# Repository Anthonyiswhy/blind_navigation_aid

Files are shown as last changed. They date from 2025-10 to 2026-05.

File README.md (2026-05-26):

# BlindNav

Wearable navigation assistant for blind users built for Raspberry Pi 4 + Intel
RealSense D435. The system detects obstacles, estimates threat from distance
and time-to-collision, and speaks warnings through Bluetooth headphones using
local audio/TTS paths.

Current production version: `v3.30 HEADLESS`

- Production script: `raspberry_pi/yolo_realsense_navigation.py`
- Foundational regression suite: `tests/test_blindnav.py`
- Advanced voice/latency regression suite: `tests/test_blindnav_v326.py`
- Verified locally on May 17, 2026: `200 passed`

## What It Does

- Runs YOLO26n ONNX inference on Pi 4 CPU.
- Samples depth per tracked object using adaptive stride + clustering.
- Compensates apparent approach speed using background-depth ego-motion.
- Suppresses static-object chatter when the user is standing still.
- Speaks left/right/ahead warnings with distance-aware cooldown buckets.
- Logs per-alert latency timestamps to `events.log`.
- Provides on-demand scene description with the `d` key.
- Provides optional push-to-talk voice commands with OpenAI speech-to-text.
- Provides an optional OpenAI alert TTS field-test mode.
- Provides a local generated-alert-clip mode for high-quality safety speech
  without live cloud/Piper synthesis during walking.

## Recent Changes

### v3.30

- Added `BLINDNAV_ALERT_TTS=openai` as a field-test mode for urgent, warning,
  and cleared alert speech.
- Added `BLINDNAV_ALERT_TTS=clips` for local pre-generated alert WAV playback
  with `espeak-ng` fallback when a phrase is missing.
- In clip mode, live Piper fallback is disabled by default for queued speech so
  awareness/info messages do not unexpectedly add Pi-side synthesis latency.
- Keeps detection, threat scoring, voice queueing, and `aplay` playback policy
  unchanged so the field test compares TTS output only.
- Uses OpenAI WAV speech output with local fallback enabled by default.
- Added `tools/run_tts_local.sh`, `tools/run_tts_openai.sh`, and
  `tools/FIELD_TEST_TTS_COMPARE.md` for repeatable side-by-side field tests.

### v3.29

- Added optional push-to-talk voice command input with `BLINDNAV_VOICE_INPUT=1`.
- Records short commands with `arecord`, transcribes through OpenAI STT, and
  routes deterministic commands: describe, nearest, people, status, repeat, and
  cancel.
- Keeps safety alerts on the existing local Piper/VoiceAssistant path by
  default; OpenAI STT is used only for command input.
- Adds a thread-safe navigation snapshot so command responses can report the
  nearest object, people count, and runtime status without blocking detection.
- Adds `tools/test_transcribe.py` for command-line STT smoke testing.

### v3.28

- Bucketed spoken distances to the same 30 cm voice buckets already used by
  cooldown keys so repeat warnings reuse the same Piper phrases instead of
  synthesizing slightly different decimals.
- Added richer voice diagnostics to `events.log`, including queue wait, synth
  time, launch wait, cache hit vs miss, and synthesis mode.
- Made left/right/ahead hysteresis frame-stable so repeated same-frame position
  reads no longer consume the switch threshold early.
- Promoted nearby side-pass people on the left/right while the user is moving,
  so a person walking by no longer depends entirely on radial TTC.
- Clamped bad-ego TTC usage to close range when the user is still, blocking
  far nonsense alerts such as `person ahead, 6.4 meters`.
- Switched non-person urgent/warning phrasing to cached `obstacle` wording so
  close-object warnings stay fast even when the classifier label changes.

### v3.27

- Switched urgent/warning alerts to Piper by default while keeping `espeak`
  available as an override through `BLINDNAV_ALERT_TTS=espeak`.
- Added a prewarmed Piper alert-clip cache for common short safety phrases so
  urgent/warning speech stays natural without paying full synthesis cost every
  time.
- Kept `en_US-amy-medium` as the default Piper voice and added env-based voice
  overrides so `lessac-medium` can be tested without editing the script.
- Added large-jump confirmation and far-noise suppression so static people at
  roughly 2-3m do not accumulate fake approach velocity.
- Replaced the thirds-based left/right/ahead split with wide-angle-aware angle
  mapping plus per-track hysteresis.
- Unified filtered motion across threat scoring, TTC logging, console output,
  and CSV logging.
- Hardened shutdown so the voice queue drains cleanly and the capture thread is
  joined before process exit.

### v3.25

- Reduced ONNX Runtime to 3 threads so Piper synthesis gets CPU time.
- Added ego-Z clamp and confidence gating to block impossible velocity spikes.
- Switched to zone-based voice cooldown keys so tracker ID churn does not
  retrigger the same warning.
- Added per-alert latency logging.

### v3.26b

- Extracted `_select_voice_message()` so alert wording is unit-testable.
- Fixed neutral wording leakage in close-distance branches when ego-motion is
  unreliable.
- Added safe urgent supersession: an urgent alert can cancel a lower-priority
  phrase only while that phrase is still synthesizing.
- Replaced terminate-style preemption with BT-safe skip-ahead before playback.
- Preserved the hard rule that active `aplay` playback is never terminated.

## Hard Rules

- Never send SIGTERM to `aplay`.
- Never use `numpy` 2.0+; pin `numpy==1.26.4`.
- Never use `cv2.imshow` on the Pi; use the Flask MJPEG stream for display work.
- Never put the ghost filter inside `ObjectTracker`.
- Never announce a threat as cleared while its compensated velocity is still
  negative enough to indicate approach.

## Repository Layout

```text
blind_navigation_aid/
|-- AGENTS.md
|-- README.md
|-- SETUP.md
|-- STATUS.md
|-- raspberry_pi/
|   `-- yolo_realsense_navigation.py
|-- tests/
|   |-- test_blindnav.py
|   `-- test_blindnav_v326.py
`-- .github/workflows/tests.yml
```

## Quick Start

```bash
source ~/blindnav-venv/bin/activate
export ANTHROPIC_API_KEY="sk-..."
export OPENAI_API_KEY="sk-..."            # optional, for voice commands
export BLINDNAV_VOICE_INPUT=1             # optional, press v to speak command
python3 raspberry_pi/yolo_realsense_navigation.py
```

Press `d` for a scene description, or `v` for a voice command when enabled.
Use `Ctrl+C` to exit.

To compare alert TTS output only:

```bash
bash tools/run_tts_local.sh
OPENAI_API_KEY="sk-..." bash tools/run_tts_openai.sh
```

To use high-quality pre-generated local alert clips:

```bash
source ~/.config/blindnav/secrets.env
python3 tools/generate_alert_clips.py
bash tools/run_tts_clips.sh
```

Clip mode uses `~/blindnav_alert_clips` by default and falls back to
`espeak-ng` if a phrase clip is missing.

To test clip mode with optional non-speech proximity tones:

```bash
export BLINDNAV_LOG_UPLOAD=1
bash tools/run_tts_clips_tones.sh
```

This keeps speech for action-level alerts and adds local stereo pulses for
nearby hazards. Set `BLINDNAV_AUDIO_MODE=quiet|balanced|training` and
`BLINDNAV_TONE_VOLUME=0.0..1.0` to tune it.

To upload each completed run's CSV and event log to GitHub automatically:

```bash
export BLINDNAV_LOG_UPLOAD=1
python3 raspberry_pi/yolo_realsense_navigation.py
```

Logs are pushed to the `blindnav-field-logs` branch by default. Set
`BLINDNAV_LOG_UPLOAD_BRANCH` or `BLINDNAV_LOG_UPLOAD_REMOTE` to override that.
The uploader writes its own `upload_*.log` file under `~/blindnav_logs`.
BlindNav keeps the newest 10 navigation runs by default and prunes older
`log_*.csv` / `events_*.log` pairs on startup and shutdown. Set
`BLINDNAV_LOG_RETENTION_RUNS` to change that. When upload is enabled, startup
also retries upload for the newest previous completed run so logs from a prior
failed shutdown are not stranded locally.

## Tests

All tests run without camera hardware, a RealSense device, Piper, or an IMU.
Hardware modules are stubbed at import time.

```bash
pytest tests/test_blindnav.py tests/test_blindnav_v326.py -v
```

Current collected totals:

- `tests/test_blindnav.py`: 37 tests
- `tests/test_blindnav_v326.py`: 163 tests
- Combined: 200 tests

## Performance Notes

- Expected field FPS: roughly 8-14 depending on thermals.
- YOLO export must produce output shape `(1, 300, 6)`.
- ONNX Runtime stays on float32. INT8 was slower on Pi 4 ARM in project tests.
- Thermal throttling is still the main real-world performance limiter.

## Current Priorities

- Add a heatsink before field sessions.
- Review and merge the v3.30 repo state, then field-test it with Ricardo Salazar.
- Record bag-file scenarios for regression playback.
- Field-test push-to-talk voice input on the Pi with the real microphone.
- Field-test local Piper, OpenAI alert TTS, and generated local clips using the
  same walking route and compare `[LATENCY] play_start` in `events.log`.
- Add traffic-light color classification after the base obstacle system is
  stable.

## Design Notes

- Urgent audio is optimized for freshness, but active playback is not forcibly
  interrupted because Bluetooth stream renegotiation is worse than waiting for a
  short phrase to finish.
- Queueing, cooldown, latency, wording, and ego-motion regressions are all
  testable without hardware and are now covered in the advanced suite.

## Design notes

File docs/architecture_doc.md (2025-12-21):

# System Architecture

This document provides a detailed technical overview of the blind navigation aid system architecture.

## Table of Contents

1. [System Overview](#system-overview)
2. [Pipeline Flow](#pipeline-flow)
3. [Component Details](#component-details)
4. [Sensor Fusion Strategy](#sensor-fusion-strategy)
5. [Visual Distance Estimation](#visual-distance-estimation)
6. [Performance Optimizations](#performance-optimizations)

---

## System Overview

The system follows a vision-primary architecture where computer vision provides the primary awareness layer, validated and refined by physical distance sensors.

```
┌─────────────────────────────────────────────────────────┐
│                    INPUT LAYER                          │
│  Camera (102° FOV) + LIDAR + TOF×2 + Ultrasonic        │
└────────────────────┬────────────────────────────────────┘
                     ↓
┌─────────────────────────────────────────────────────────┐
│                  DETECTION LAYER                        │
│  YOLOv11n (320×320) → Bounding boxes + Classes         │
└────────────────────┬────────────────────────────────────┘
                     ↓
┌─────────────────────────────────────────────────────────┐
│                  TRACKING LAYER                         │
│  IoU matching → Track IDs + Velocity calculation        │
└────────────────────┬────────────────────────────────────┘
                     ↓
┌─────────────────────────────────────────────────────────┐
│              DISTANCE ESTIMATION LAYER                  │
│  Visual (bbox size) + Sensor validation → Distance      │
└────────────────────┬────────────────────────────────────┘
                     ↓
┌─────────────────────────────────────────────────────────┐
│                 ASSESSMENT LAYER                        │
│  Threat scoring → Priority queue                        │
└────────────────────┬────────────────────────────────────┘
                     ↓
┌─────────────────────────────────────────────────────────┐
│                   OUTPUT LAYER                          │
│  Buzzer frequency + Visual overlay + CSV logging        │
└─────────────────────────────────────────────────────────┘
```

---

## Pipeline Flow

### Frame Processing (Every Frame)

```python
1. Capture frame from Picamera2 (640×480 RGB)
2. Rotate 180° (camera mounting)
3. Read sensor data:
   - LIDAR (via I²C serial)
   - TOF1, TOF2, Ultrasonic (via ESP32 serial)
4. Apply median filtering (3-sample buffer)
5. Update sensor health monitors
```

### Object Detection (Every 3rd Frame)

```python
6. Letterbox resize to 320×320
7. Normalize to [0,1] and transpose to CHW
8. YOLOv11n inference
9. Postprocess:
   - Parse (1, 84, 2100) output
   - Filter by confidence (>0.30)
   - Convert to original image coordinates
   - Apply NMS (IoU threshold 0.45)
```

### Tracking & Distance (Every Frame)

```python
10. Update tracker with new detections
11. Match existing tracks using IoU (>0.4)
12. Expire old tracks (>1.0s)
13. For each track:
    a. Estimate visual distance from bbox size
    b. Assign appropriate sensor based on position
    c. Fuse visual + sensor estimates
    d. Calculate velocity from distance history
```

### Threat Assessment (Every Frame)

```python
14. Calculate threat score for each track
15. Sort by score (descending)
16. Update buzzer based on top threat
17. Log to CSV
18. Auto-save snapshot if critical threat
```

---

## Component Details

### 1. YOLOv11n Detection

**Model:** `yolo11n.onnx` (320×320 input)

**Input Shape:** `(1, 3, 320, 320)` - NCHW format

**Output Shape:** `(1, 84, 2100)` where:
- 84 = 4 box coords + 80 class confidences
- 2100 = number of anchor points (for 320×320: 80×80/4 + 40×40/4 + 20×20/4 = 2100)

**Coordinate Format:**
- `[x_center, y_center, width, height]` in pixels relative to 320×320 input
- Coordinates must be transformed back to original image space

**Postprocessing Steps:**
1. Transpose to `(2100, 84)`
2. Parse box coords (first 4 values)
3. Find best class (argmax of next 80 values)
4. Filter by confidence threshold
5. Remove letterbox padding effects
6. Scale back to original resolution
7. Apply NMS

### 2. Object Tracker

**Algorithm:** IoU-based matching

**Key Parameters:**
- `max_age`: 1.0s - Track expiry time
- `iou_threshold`: 0.4 - Minimum IoU for match
- `max_tracks`: Unlimited

**Track State:**
```python
Track {
    id: int
    class_name: str
    box: [x1, y1, x2, y2]
    score: float
    distance: int (cm)
    distance_source: str
    distance_confidence: float
    velocity: float (cm/s, negative = approaching)
    position_history: deque(5)
    distance_history: deque(5)
}
```

**Velocity Calculation:**
```python
if len(distance_history) >= 2:
    old_time, old_dist = distance_history[0]
    time_delta = current_time - old_time
    velocity = (current_dist - old_dist) / time_delta  # cm/s
```

### 3. Visual Distance Estimator

**Principle:** Inverse proportion - object size in image inversely proportional to distance

**Formula:**
```python
distance = reference_distance × (reference_pixels / actual_pixels)
```

**Calibration Data:**

| Object | Real Height (cm) | Ref Distance (cm) | Ref Pixels @ Distance |
|---|---|---|---|
| Person | 170 | 50 | 192 |
| Car | 150 | 200 | 240 |
| Bottle | 25 | 30 | 100 |
| Cup | 12 | 25 | 80 |
| Chair | 90 | 100 | 150 |
| Laptop | 25 | 40 | 120 |
| Phone | 15 | 20 | 90 |

**Confidence Calculation:**
```python
box_area_ratio = (box_area / frame_area) × 100
center_distance = distance_from_frame_center × 2
center_score = 1.0 - center_distance

confidence = box_area_ratio × center_score
# Large boxes near center = high confidence
# Small boxes at edges = low confidence
```

### 4. Sensor Fusion

**Sensor Assignment by Position:**

```
          TOF2 (Left)     LIDAR/Ultra     TOF1 (Right)
               ↖              ↑              ↗
                 \            |            /
            -0.4  \           0          /  +0.4
                   \          |        /
                    \         |       /
                     \_______FOV_____/
                           102°
```

**Position Mapping:**
```python
position = (box_center_x - frame_width/2) / (frame_width/2)
# -1.0 = left edge, 0.0 = center, +1.0 = right edge

if position > 0.3:    # Right side
    use TOF1
elif position < -0.3: # Left side
    use TOF2
else:                 # Center
    use LIDAR or Ultrasonic
```

**Confidence-Weighted Fusion:**
```python
estimates = [
    {"distance": visual_dist, "confidence": visual_conf, "valid": True},
    {"distance": sensor_dist, "confidence": sensor_conf, "valid": sensor_ok}
]

weighted_sum = Σ(distance × confidence)
total_weight = Σ(confidence)
fused_distance = weighted_sum / total_weight
```

### 5. Sensor Health Monitor

**Health Metrics:**

```python
SensorHealth {
    last_value: float
    last_change_time: float
    stuck: bool
    valid: bool
    confidence: float (0-1)
    history: deque(10)
}
```

**Checks Performed:**

1. **Stuck Detection:**
   ```python
   if abs(current - last_value) < 1.0:  # No change
       time_stuck = now - last_change_time
       if time_stuck > 0.8:  # Stuck for 0.8s
           stuck = True
           confidence *= 0.9  # Degrade gradually
   ```

2. **Range Validation:**
   ```python
   if value < min_value or value > max_value:
       valid = False
       confidence = 0.0
   ```

3. **Temporal Plausibility:**
   ```python
   apparent_speed = abs(current - last_value) / time_delta
   if apparent_speed > 400 cm/s:  # Faster than reasonable
       confidence *= 0.5  # Likely glitch
   ```

### 6. Threat Assessment

**Scoring Function:**

```python
def calculate_threat_score(track):
    score = 0.0
    
    # COMPONENT 1: Distance urgency
    if distance < 50:
        # Exponential urgency in critical zone
        score += 100 × exp(-(distance / 20))
    elif distance < 150:
        # Linear urgency in warning zone
        score += 50 × (150 - distance) / 150
    elif distance < 300:
        # Low urgency in awareness zone
        score += 10 × (300 - distance) / 300
    
    # COMPONENT 2: Velocity factor
    if velocity < -5:  # Approaching
        score += abs(velocity) × 5
        if velocity < -20:  # Fast approach
            score += 50  # Danger bonus
    elif velocity > 5:  # Moving away
        score × 0.5  # Reduce urgency
    
    # COMPONENT 3: Object type weight
    weights = {
        "train": 4.0, "truck": 3.5, "bus": 3.5,
        "car": 3.0, "motorcycle": 2.5, "bicycle": 2.0,
        "person": 1.5, "dog": 1.3,
        "chair": 0.8, "bench": 0.9, "plant": 0.7,
        "bottle": 0.3, "cup": 0.3
    }
    score × weights.get(type, 1.0)
    
    # COMPONENT 4: Confidence adjustment
    if track.score > 0.7:
        score × 1.2  # High confidence detection
    elif track.score < 0.3:
        score × 0.8  # Low confidence detection
    
    return score
```

**Threat Levels:**

| Level | Score Range | Buzzer Frequency | Action |
|---|---|---|---|
| CRITICAL | >80 | 1200-1500 Hz | Immediate alert |
| WARNING | 40-80 | 800-1200 Hz | Strong warning |
| CAUTION | 10-40 | 400-800 Hz | Awareness |
| SAFE | <10 | Off | No action |

---

## Sensor Fusion Strategy

### Why Vision-Primary?

Traditional assistive devices use **sensor-primary** fusion:
- Sensors detect distance
- Camera identifies what's at that distance
- **Problem:** Blind spots where camera sees objects but sensors don't

Our **vision-primary** approach:
- Camera detects all visible objects (102° FOV)
- Visual estimator provides distance for ALL objects
- Sensors validate and refine when available
- **Advantage:** No blind spots, graceful degradation

### Fusion Logic Flow

```
1. Object detected by YOLO
   ↓
2. Visual distance estimated from bbox size
   ↓
3. Check object position in frame
   ↓
4. Assign appropriate sensor(s)
   ↓
5. Get sensor reading with health check
   ↓
6. Fuse visual + sensor:
   - If sensor valid & agrees: weighted average
   - If sensor valid & conflicts: log warning, use weighted
   - If sensor invalid: use visual only
   ↓
7. Update track with fused distance
```

### Example Fusion Scenarios

**Scenario A: Agreement (Ideal)**
```
Visual: 45cm (conf=0.8)
TOF1:   42cm (conf=1.0, healthy)
→ Fused: 43cm, high confidence
```

**Scenario B: Conflict**
```
Visual: 25cm (conf=0.7)
TOF2:    6cm (conf=0.2, STUCK)
→ Fused: 23cm, medium confidence (TOF downweighted)
→ Log: "⚠️ CONFLICT detected"
```

**Scenario C: Visual-Only**
```
Visual: 60cm (conf=0.6)
Sensor: None (object outside sensor FOV)
→ Fused: 60cm, medium confidence
→ Source: "Visual-ONLY"
```

---

## Performance Optimizations

### 1. Model Selection

**Comparison:**

| Model | Input Size | FPS | Accuracy | Choice |
|---|---|-----|---|---|
| YOLOv8m | 640×640 | 1.2 | 92% | ❌ Too slow |
| YOLOv8n | 640×640 | 3.4 | 87% | ❌ Still slow |
| YOLOv8n | 320×320 | 7.2 | 83% | ⚠️ Better |
| **YOLOv11n** | **320×320** | **8-10** | **85%** | ✅ **Best** |

### 2. Detection Frequency

**Strategy:** Detect every 3rd frame, track on all frames

```python
if frame_idx % 3 == 0:
    detections = yolo_inference(frame)
tracks = tracker.update(detections, current_time)
```

**Impact:**
- 3× fewer YOLO calls
- Tracking maintains continuity
- Effective FPS: 24-30 Hz (display + tracking)
- Detection FPS: 8-10 Hz (YOLO)

### 3. Track Expiry Tuning

**Problem:** Long expiry (2s) caused lag - objects left "ghost boxes"

**Solution:** Aggressive expiry (1s)
```python
expired = [t for t in tracks if current_time - t.last_seen > 1.0]
```

**Impact:**
- Eliminated lag effect
- Trade-off: Brief flicker if detection drops
- Balanced by higher IoU threshold (0.4)

### 4. Letterbox vs. Resize

**Why Letterbox?**
```python
# Simple resize distorts aspect ratio
resized = cv2.resize(img, (320, 320))  # ❌ Distorts objects

# Letterbox maintains aspect ratio
padded = letterbox_resize(img, 320)     # ✅ Preserves shapes
```

**Impact:**
- Better detection accuracy (+3%)
- Minimal performance cost (<5ms)

### 5. Median Filtering

**Why Not Mean?**
```python
# Mean is sensitive to outliers
lidar_values = [65, 64, 200, 66]  # One bad reading
mean = 99 cm  # ❌ Heavily affected

# Median is robust
median = 65 cm  # ✅ Ignores outlier
```

**Buffer Size:** 3 samples
- Smaller = responsive
- Larger = smoother but lagged

---

## Data Flow Example

**Input:**
```
Frame: 640×480 RGB
LIDAR: 65cm
TOF1: 58cm
TOF2: 6cm (STUCK)
Ultra: 62cm
```

**Detection:**
```
YOLOv11n → [person @ (100,150,250,400), conf=0.82]
```

**Visual Estimation:**
```
bbox_height = 250px
reference_height = 192px (person @ 50cm)
visual_distance = 50 × (192/250) = 38cm
visual_confidence = 0.75 (large box, near center)
```

**Sensor Assignment:**
```
position = (175 - 320) / 320 = -0.45 (left side)
→ Use TOF2 + LIDAR
```

**Sensor Health:**
```
TOF2: 6cm, STUCK, confidence=0.2
LIDAR: 65cm, OK, confidence=1.0
```

**Fusion:**
```
estimates = [
    Visual: 38cm × 0.75 = 28.5
    TOF2:    6cm × 0.2  =  1.2  (downweighted due to stuck)
    LIDAR:  65cm × 1.0  = 65.0
]
sum_weights = 0.75 + 0.2 + 1.0 = 1.95
fused = (28.5 + 1.2 + 65.0) / 1.95 = 49cm
```

**Velocity:**
```
Last distance: 60cm @ t=0
Current: 49cm @ t=0.3s
velocity = (49-60)/0.3 = -37 cm/s (approaching!)
```

**Threat:**
```
distance_score = 50 × (150-49)/150 = 34
velocity_score = 37 × 5 + 50 = 235 (fast approach bonus!)
type_weight = 1.5 (person)
final_score = (34 + 235) × 1.5 = 404 × 1.5 = 606
→ CRITICAL threat!
```

**Output:**
```
Buzzer: 1450 Hz (high urgency)
Display: RED box around person
CSV: ...,"person",606,"Visual+LIDAR"
```

---

## System Specifications

| Component | Specification |
|---|---|
| **Processing** | Raspberry Pi 4B, 4GB RAM, quad-core ARM Cortex-A72 |
| **Detection** | YOLOv11n ONNX, 320×320, 8-10 FPS |
| **Camera** | Arducam IMX708, 102° FOV, 640×480 @ 30 FPS |
| **Sensors** | LIDAR (0-800cm), TOF×2 (0-200cm), Ultrasonic (0-400cm) |
| **Latency** | <100ms end-to-end (capture → decision) |
| **Power** | ~3W total system draw |
| **Accuracy** | ±3cm (sensor), ±15cm (visual-only) |
| **Coverage** | 102° horizontal (camera), 45° (TOF), 8m forward (LIDAR) |

---

**Last Updated:** December 2024  
**Version:** 2.1

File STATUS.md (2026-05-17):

# Project Status

Last updated: May 17, 2026
Current repo target: `v3.30 HEADLESS`

## Verified in Code and Tests

- YOLO26n ONNX pipeline is configured for Pi-friendly CPU inference.
- Voice arbitration includes:
  - 3-slot priority queue
  - pre-synthesis
  - zone-based cooldown keys
  - per-alert latency timestamps
  - safe urgent supersession before playback
  - Piper as the default urgent/warning alert voice
  - optional OpenAI alert TTS field-test mode via `BLINDNAV_ALERT_TTS=openai`
  - generated local alert clip mode via `BLINDNAV_ALERT_TTS=clips`
  - local fallback for OpenAI alert TTS failures
  - `espeak-ng` fallback for missing generated clips
  - live Piper fallback disabled by default during clip-mode field tests
  - prewarmed cached alert clips for common short safety phrases
  - bucketed spoken distances for cache reuse
  - explicit queue/synth/cache latency diagnostics in `events.log`
- Side-pass people now get awareness/warning promotion while the user is moving.
- Bad-ego TTC is now trusted only at close range while the user is still.
- Motion filtering now suppresses large one-frame depth jumps and small
  far-range drift before threat scoring/logging.
- Position labeling now uses wide-angle-aware angle mapping with hysteresis.
- Repeated same-frame `get_position()` reads now return a cached label instead
  of advancing hysteresis multiple times inside one video frame.
- Optional push-to-talk voice input is implemented with:
  - `arecord` command capture
  - OpenAI speech-to-text transcription
  - deterministic command routing for describe, nearest, people, status,
    repeat, and cancel
  - thread-safe navigation snapshots so STT never blocks detection
- Ego-motion compensation includes:
  - background-depth velocity estimation
  - hard clamp at `+/-160 cm/s`
  - confidence gating via rolling-window standard deviation
- Threat wording is routed through `_select_voice_message()`, which is directly
  covered by truth-table tests.
- Hardware-free validation currently passes:
  - `tests/test_blindnav.py`
  - `tests/test_blindnav_v326.py`
  - combined result: `200 passed`

## Confirmed Design Invariants

- Active `aplay` playback is never terminated.
- Lower-priority synthesized WAVs are skipped before playback if a higher-priority
  alert becomes pending.
- Ghost filtering stays outside `ObjectTracker`.
- Distance bucket cooldowns keep distance wording fresh as threats approach.
- Ego-motion compensation is zeroed when confidence is poor because bad
  compensation is worse than no compensation.
- Voice commands use `voice.speak_info()` only; urgent/warning obstacle alerts
  remain owned by the main detection loop.
- OpenAI alert TTS and generated-clip modes change only WAV generation/playback
  source; threat scoring, cooldowns, queueing, and `aplay` playback policy
  remain unchanged.

## What Is Hardware-Validated vs Simulated

### Strongly covered without hardware

- queue eviction and TTL expiry
- cooldown behavior
- zone-key dedup under tracker ID churn
- cold-start silence injection
- latency timestamp logging
- threat score truth tables
- message wording selection
- ego-motion clamp and confidence behavior
- voice command parsing, routing, failure handling, and nonblocking listener
  behavior

### Still requires on-device validation

- RealSense depth noise in real corridors and doorways
- actual Bluetooth wake timing under field conditions
- OpenAI TTS latency, timeout behavior, and cellular/Wi-Fi reliability in the
  urgent alert path
- generated clip coverage for every phrase produced during real hallway runs
- walking sessions with harness sway
- thermal behavior above 65 C
- tracker stability with crowded scenes and occlusions
- real microphone quality, OpenAI STT latency, and push-to-talk ergonomics on
  the Pi

## Current Known Limitations

- Urgent cannot cut off a phrase that is already playing. This is intentional:
  killing `aplay` breaks Bluetooth smoothness and violates the repo rule.
- The system is still thermally sensitive on Pi 4 and can fall to low FPS when
  hot.
- Full-frame occlusion can still remove enough background pixels to disable
  ego-motion compensation temporarily.
- The advanced test suite is strong, but field walking data is still needed for
  final tuning confidence.
- Voice input requires `OPENAI_API_KEY`, `openai`, working `arecord`, and a
  microphone; without those it remains disabled or fails gracefully.
- OpenAI alert TTS also requires `OPENAI_API_KEY`; fallback is enabled by
  default, but network stalls can still increase `synth` and `play_start`
  latency before fallback returns.
- Generated clip mode requires a prebuilt `~/blindnav_alert_clips` directory for
  high-quality speech; missing phrases fall back to `espeak-ng`.

## Pending Work

- Heatsink: highest hardware priority
- Review and merge the generated-clip follow-up for v3.30
- Schedule a field test with Ricardo Salazar
- Record five bag-file regression scenarios
- Add traffic-light color classification
- Field-test push-to-talk voice input and tune command phrasing
- Compare `tools/run_tts_local.sh`, `tools/run_tts_openai.sh`, and
  `tools/run_tts_clips.sh` on the same course and keep the lower worst-case
  alert latency path

## CI State

GitHub Actions should run both test files:

```bash
pytest tests/test_blindnav.py tests/test_blindnav_v326.py -v
```

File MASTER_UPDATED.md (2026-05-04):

# BlindNav Master Status

Current production version: `v3.30 HEADLESS`

Status:
- Production script: `raspberry_pi/yolo_realsense_navigation.py`
- Hardware-free validation: `195 passed`
- Verified on: April 27, 2026

Version history:

| Version | Status | Notes |
| --- | --- | --- |
| v3.30 | Current branch target | Optional OpenAI alert TTS field-test mode with local fallback and side-by-side run scripts |
| v3.29 | Previous branch target | Push-to-talk voice commands with OpenAI STT, deterministic command routing, nonblocking snapshots |
| v3.28 | Previous branch target | Bucketed speech, side-pass person alerts, bad-ego TTC clamp, richer voice diagnostics |
| v3.27 | Previous branch target | Piper default alerts, cached alert clips, filtered motion, wide-angle position hysteresis, clean shutdown |
| v3.26b | Previous production baseline | BT-safe skip-ahead and neutral-wording fixes |
| v3.25 | Earlier baseline | Ego confidence gating, latency logging, zone keys |

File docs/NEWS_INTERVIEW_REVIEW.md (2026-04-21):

# BlindNav News Interview Review Sheet

## One-Sentence Summary

BlindNav is a wearable AI navigation assistant for blind users that combines
real-time object detection, depth sensing, motion awareness, and voice alerts
to help a user understand nearby obstacles while walking.

## 20-Second Version

I built a chest-mounted navigation system that runs on a Raspberry Pi 4 with an
Intel RealSense depth camera. It detects people and obstacles, estimates how
threatening they are based on distance and motion, and speaks short left/right/
ahead warnings through headphones. It also supports on-demand AI scene
description.

## 60-Second Version

The project started from a simple assistive-tech question: can I build
something that helps a blind user understand the space directly in front of
them while moving? The current system uses a Raspberry Pi 4, an Intel RealSense
D435 depth camera, an IMU, YOLO object detection, depth-based distance
measurement, ego-motion compensation, and local Piper text-to-speech. The goal
is not to replace a cane or a guide dog. The goal is to provide extra spatial
awareness by warning about nearby people and obstacles in a way that is timely,
brief, and usable while walking.

## What Problem It Solves

- Standard obstacle detection alone is often too blunt: it can tell you that
  something exists, but not whether it matters right now.
- Blind users need timing, direction, and confidence, not just labels.
- Indoor spaces are dynamic. People pass by, chairs move, tables stick out,
  and walls or glass may not be obvious to a standard RGB-only system.
- A good assistive system must avoid constant chatter. Silence is as important
  as speech.

## What Makes This Different

- It combines object detection and depth sensing, so it knows both what an
  object is and roughly how far away it is.
- It estimates threat, not just presence. A close object matters more than a
  far object. A moving person matters differently than a static chair.
- It tracks whether the user is moving, because navigation guidance should
  change if the user is standing still versus walking.
- It is designed around short voice output, not a screen.
- It includes hardware-free regression tests, so behavior can be improved
  between field runs without needing the camera every time.

## What Changed Since The ESP32 Stage

- The earlier ESP32 phase was much more limited and was closer to a sensor
  experiment than a full navigation assistant.
- The current system moved to a Raspberry Pi 4 so it can run camera-based
  computer vision, ONNX inference, depth processing, and local neural speech.
- The project shifted from "can I detect obstacles at all?" to "can I deliver
  useful, low-chatter, real-time guidance while walking?"
- The current version includes:
  - YOLO26n object detection
  - Intel RealSense D435 depth sensing
  - IMU-based movement awareness
  - ego-motion compensation
  - left/right/ahead voice guidance
  - on-demand AI scene description
  - a 174-test hardware-free regression suite

## Current Hardware Stack

- Raspberry Pi 4
- Intel RealSense D435
- ICM-20948 IMU
- Bluetooth headphones
- Chest harness

## Current Software Stack

- Python
- ONNX Runtime
- YOLO26n object detector
- Intel RealSense SDK
- Piper TTS
- Claude for on-demand scene description

## Core Runtime Pipeline

1. Capture synchronized RGB and depth frames from the RealSense camera.
2. Run YOLO object detection on the RGB frame.
3. Track objects across frames.
4. Sample depth inside each tracked box to estimate distance.
5. Estimate ego-motion so stationary objects do not look like they are moving
   just because the user is walking.
6. Score threats based on distance, motion, and context.
7. Choose whether to speak, what to say, and how urgently to say it.
8. Play a short voice alert through headphones.

## The Most Important Engineering Constraint

The hardest problem is not object detection by itself. The hardest problem is
deciding when to speak and when not to speak. If the system talks too much, it
becomes distracting. If it talks too little, it misses something important.

## Safety Philosophy

- This is an assistive prototype, not a replacement for a cane, guide dog, or
  formal Orientation and Mobility training.
- It should add awareness, not take control away from the user.
- It should be conservative about uncertainty.
- It should avoid pretending to know more than it really knows.
- It should fail quietly rather than sound overconfident when motion or depth
  data becomes unreliable.

## What v3.28 Added

- Bucketed spoken distances:
  warnings now snap to stable 30 cm voice buckets so repeated alerts reuse the
  same phrases instead of synthesizing many slightly different decimals.
- Better voice diagnostics:
  logs now separate queue wait, synthesis time, playback launch delay, and
  cache hit versus miss.
- Better side-pass person handling:
  people moving by on the left or right are promoted earlier, even when radial
  time-to-collision is weak.
- Better bad-ego handling:
  the system now suppresses far false motion-based alerts when ego-motion
  confidence is poor.

## Numbers To Remember

- Current version: `v3.28 HEADLESS`
- Main production script: `raspberry_pi/yolo_realsense_navigation.py`
- Current hardware-free validation: `174 passed`
- Camera: Intel RealSense D435
- Compute: Raspberry Pi 4

## What Is Validated Well

- Object tracking logic
- Distance sampling logic
- Voice cooldown logic
- Priority queue behavior
- Voice TTL and skip-ahead behavior
- Threat scoring truth tables
- Left/right/ahead classification logic
- Motion filtering and bad-ego suppression logic

## What Still Needs Real-World Testing

- Crowded scenes
- Long walking sessions
- Bluetooth timing under field conditions
- Thermal performance on the Pi
- User preferences for how much voice output is helpful

## Honest Limitations

- The system can still slow down when the Pi gets hot.
- A spoken warning can still be late if a phrase is already playing, because
  active audio playback is intentionally never hard-killed.
- Camera occlusion and depth noise still matter in real environments.
- It is still a prototype and should be described honestly as one.

## Good Ways To Describe The Project

- "A wearable AI navigation assistant prototype for blind users."
- "A system that combines depth sensing, computer vision, and voice alerts."
- "An attempt to make obstacle awareness more timely and less noisy."

## Bad Ways To Describe The Project

- "It solves blindness."
- "It replaces a white cane."
- "It is production-ready for unsupervised public deployment."
- "It always understands the environment correctly."

## Likely Interview Questions

### What inspired this project?

I became interested in accessibility technology through my grandmother's vision
loss and started asking what kind of system could actually be helpful in real
physical spaces, not just in a lab demo.

### Why not just use a phone app?

A phone is useful for many things, but navigation assistance while walking
works better when the sensing is hands-free, chest-mounted, and always aimed at
the path ahead.

### Why is depth sensing important?

Because object labels alone are not enough. A chair two meters away matters
very differently than a chair thirty centimeters away.

### Why does voice design matter so much?

Because a blind user cannot afford to be flooded with useless audio. The system
has to be brief, timely, and quiet when nothing important is happening.

### What was the hardest technical problem?

Balancing false positives and false negatives in a way that still feels usable
in motion. That includes motion compensation, deciding when a person passing by
matters, and reducing voice delay.

### What are you most proud of?

That it is not just a one-off demo. I built a real regression suite around it,
so I can improve behavior systematically instead of guessing between field
tests.

### Is it finished?

No. It is a serious prototype with strong software validation, but it still
needs continued field testing, refinement, and safety-focused iteration.

## Strong Soundbites

- "The challenge is not just seeing objects. The challenge is deciding when a
  spoken warning is actually useful."
- "For assistive technology, silence can be as important as speech."
- "A navigation system has to understand both the world and the user's motion
  through it."
- "I wanted to move from a sensor demo to something that behaves more like a
  real assistant."

## If Asked About AI

- The system uses AI in two different ways:
  - local vision for real-time detection
  - on-demand multimodal AI for richer scene description
- Real-time safety-relevant behavior should be short, deterministic, and
  low-latency.
- Longer open-ended descriptions are useful, but they are not the same as
  split-second walking guidance.

## If Asked About Impact

The goal is not to claim that one student project fixes a huge accessibility
problem. The goal is to contribute something real: a working prototype, a set
of engineering lessons, and open project documentation that can help future
assistive-tech work.

## Best Closing Line

This project is really about respecting the difference between detecting the
world and making that information usable in the moment for a blind traveler.

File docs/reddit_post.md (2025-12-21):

# Built an AI-Powered Navigation Aid for the Blind on Raspberry Pi 4B

**TL;DR:** Created a real-time assistive navigation system using YOLOv11n, multiple distance sensors, and computer vision to help visually impaired people detect obstacles, calculate approach velocity, and prioritize threats. Runs at 8-10 FPS on Pi 4B with intelligent sensor fusion and automatic failure recovery.

---

## The Problem

Blind navigation is hard. White canes only detect ground-level obstacles within arm's reach (~1m). Guide dogs are expensive ($50k+) and not everyone can have one. I wanted to build something that provides **360° awareness** with distance and velocity information in real-time.

---

## Hardware Stack

- **Raspberry Pi 4B (4GB)** - main compute
- **Arducam IMX708 (102° FOV)** - wide-angle camera for object detection
- **TF-Luna LIDAR** - forward distance (2cm-8m range, ±3cm accuracy)
- **VL53L0X TOF sensors (×2)** - left/right coverage at 22.5° angles (1-200cm)
- **HC-SR04 Ultrasonic** - backup forward sensor (2-400cm)
- **ESP32** - handles TOF/ultrasonic via serial (offloads Pi)
- **Buzzer** - audio feedback (frequency = urgency)

---

## Software Architecture

### Core Components:

**1. YOLOv11n Object Detection (320×320 ONNX)**
- Detects 80 object classes in real-time
- Optimized for edge devices - runs at **8-10 FPS** on Pi 4B
- Letterbox preprocessing maintains aspect ratio

```python
# Efficient letterbox resizing for YOLOv11n
def letterbox_resize(img, target_size=320):
    scale = min(target_size / h, target_size / w)
    # Pad with gray borders to maintain aspect ratio
    padded = np.full((320, 320, 3), 114, dtype=np.uint8)
```

**2. Multi-Object Tracking with Velocity**
- Tracks objects across frames using IoU matching
- Calculates velocity from distance changes: `velocity = Δdistance / Δtime`
- Negative velocity = approaching (dangerous!)

**3. Vision-Primary Sensor Fusion (The Innovation!)**
- **Monocular depth estimation** from bounding box size
- Solves "blind spot" problem: objects visible to 102° camera but outside 45° sensor FOV
- Uses calibrated reference sizes for different object types

```python
# Visual distance estimation
REFERENCE_SIZES = {
    "person": {"reference_pixels": 192, "reference_distance": 50},
    "car": {"reference_pixels": 240, "reference_distance": 200}
}

distance = ref_distance * (ref_pixels / box_height_pixels)
```

**Why this matters:** If you put your hand 10cm from the camera but all physical sensors point away, traditional systems fail. My system estimates distance from the hand's size in the image, then validates with sensors when available.

**4. Sensor Health Monitoring**
- Detects stuck sensors (no value change for >0.8s)
- Range validation (physical limits)
- Temporal plausibility check (no teleporting)
- Auto-degrades confidence on failures

Example output:
```
🔧 SENSOR HEALTH:
   LIDAR: OK
   Ultrasonic: OK
   TOF1(R): OK
   TOF2(L): STUCK (conf=0.3) ⚠️
```

**5. Threat Assessment System**

```python
threat_score = f(distance, velocity, object_type, confidence)

# Distance: exponential urgency under 50cm
if distance < 50:
    score += 100 * exp(-(distance / 20))

# Velocity: fast approach = high priority
if velocity < -5:  # Approaching
    score += abs(velocity) * 5

# Object type: cars more dangerous than bottles
score *= {"car": 3.0, "person": 1.5, "bottle": 0.3}[type]
```

---

## Key Challenges Solved

**Challenge 1: "The Finger Problem"**
- User puts hand 10cm from camera
- All sensors point away → assign wrong distance (60cm from LIDAR)
- **Solution:** Vision-primary fusion - every object in camera view gets visual distance estimate first, sensors validate when they can see it

**Challenge 2: Sensor Failures**
- TOF sensor stuck at 6cm for minutes (happened during testing!)
- **Solution:** Real-time health monitoring with confidence degradation
- System automatically switches to visual-only when sensor fails

**Challenge 3: Performance on Pi 4B**
- Initial YOLOv8 @ 640×640: **3.4 FPS** ❌
- Optimized YOLOv11n @ 320×320: **8-10 FPS** ✅
- Techniques: Letterbox preprocessing, detection every 3 frames, aggressive track expiry

**Challenge 4: Duplicate Bounding Boxes (Lag Effect)**
- Objects left "ghost boxes" when moving
- **Solution:** Reduced track expiry from 2s → 1s, increased IoU threshold 0.3 → 0.4

---

## Results

- ✅ Detection accuracy: ~85% for common objects
- ✅ Distance accuracy: ±15cm (visual-only), ±3cm (with sensor validation)
- ✅ Velocity tracking: Real-time cm/s measurements
- ✅ FPS: 8-10 (suitable for navigation)
- ✅ Graceful degradation: Works even if 2/4 sensors fail

---

## Demo Scenarios

**Scenario 1: Person approaching**
```
Frame 1: person 60cm, • 0cm/s [WARNING]
Frame 2: person 45cm, ← 15cm/s [CRITICAL] ← Detected fast approach!
Buzzer: High frequency alert
```

**Scenario 2: Sensor conflict detected**
```
person: 25cm [Visual+TOF1(R)] ⚠️CONFLICT
└─ Visual=25cm, TOF1(R)=22cm ✓ Agreement
└─ TOF2(L)=6cm ⚠️ STUCK - ignored
System logs conflict, trusts vision+TOF1 fusion
```

---

## What's Next?

**Desk Prototype → Wearable Belt v2:**
- 360° TOF sensor ring (8 sensors around waist)
- IMU for fall detection + walking direction
- GPS integration for route guidance
- Bone conduction audio (keeps ears free)
- 8+ hour battery life target

**Software Improvements:**
- Add YOLO-World for semantic hazards (stairs, curbs, wet floor signs)
- Implement path planning (suggest safe direction to turn)
- Memory system (remember obstacles at home)
- Emergency SOS on fall detection

---

## Code & Architecture

**Full code on GitHub:** [github.com/Anthonyiswhy/blind_navigation_aid](https://github.com/Anthonyiswhy/blind_navigation_aid)

Includes:
- Complete Python implementation
- Sensor health logs with conflict detection
- Distance calibration data
- Architecture diagrams

---

## Lessons Learned

1. **Vision-primary beats sensor-primary** for wide coverage (102° camera vs 45° sensors)
2. **Redundancy matters** - hybrid approach survives single-point failures
3. **Real-time constraints force tradeoffs** - 320×320 YOLO is "good enough" and 3× faster than 640×640
4. **Health monitoring is crucial** - stuck sensors are silent failures without detection
5. **Track expiry is critical** - too long = lag, too short = flickering

---

## Questions for the Community

1. **Sensor fusion:** Anyone experienced with robotics sensor fusion? Better alternatives to weighted averaging?
2. **360° coverage:** Best approach for wearable? Considering LiDAR360 vs ring of 8 TOFs
3. **Power optimization:** Tips for 8+ hour battery life on Pi 4B? Currently draws ~3W
4. **Audio feedback:** Experience with bone conduction for navigation? Concerned about ear safety with constant buzzer

---

## Tech Stack Summary

- **Hardware:** Pi 4B (4GB), Arducam IMX708, TF-Luna LIDAR, 2× VL53L0X TOF, HC-SR04, ESP32
- **Software:** Python 3.11, YOLOv11n ONNX (ONNXRuntime), OpenCV, NumPy, Picamera2
- **Detection:** 320×320 input, 8-10 FPS, 80 COCO classes
- **Sensors:** I²C (LIDAR), Serial (ESP32→Pi), GPIO (Buzzer)

---

This project taught me more about real-time systems, sensor fusion, and edge AI than any tutorial could. The moment it detected my hand approaching and ramped up the buzzer frequency was incredible - it felt like giving someone back a sense!

Happy to answer questions or discuss alternative approaches. Would love feedback from the community on improving the design! 🚀

**Update:** Added sensor health monitoring after a TOF got stuck during testing and went unnoticed for 10 minutes. Now the system automatically detects and reports sensor failures with confidence degradation.

---

*PS: If you're working on assistive tech or accessibility projects, I'd love to chat! Always looking to learn from others in this space.*

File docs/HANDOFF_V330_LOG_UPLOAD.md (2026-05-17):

# BlindNav v3.30 Voice, Log Upload, and Clip Mode Handoff

Branch: `codex/v330-clip-infra-cleanup`

Base PR: https://github.com/Anthonyiswhy/blind_navigation_aid/pull/14

Latest follow-up: local alert clip mode and repo infrastructure cleanup.

## What Changed

- Added optional OpenAI alert TTS field-test mode from the v3.30 branch.
- Added optional push-to-talk OpenAI speech-to-text command input.
- Added `BLINDNAV_LOG_UPLOAD=1` to upload completed run logs to GitHub.
- Added automatic pruning for `~/blindnav_logs`.
- Added startup recovery upload for the newest previous completed run when log upload is enabled.
- Added generated local alert clip mode with `BLINDNAV_ALERT_TTS=clips`.
- Expanded the clip generator to cover observed 2.3m phrases and common
  awareness/info replies.
- In clip mode, live Piper fallback is disabled by default so a desk/field test
  does not silently reintroduce Pi-side synthesis latency.
- Added a GitHub pull request template with BlindNav-specific safety checks.
- Pinned CI and Pi requirements to `numpy==1.26.4`.
- Made `tools/run_tts_local.sh` and `tools/run_tts_openai.sh` executable.

## Runtime Defaults

- Voice input is off by default: `BLINDNAV_VOICE_INPUT=0`.
- Alert TTS defaults to local Piper unless a helper script overrides it.
- Clip mode is explicit: `BLINDNAV_ALERT_TTS=clips`.
- Clip mode does not use live Piper fallback unless
  `BLINDNAV_CLIP_MODE_ALLOW_LIVE_PIPER=1` is set.
- Log upload is off by default: `BLINDNAV_LOG_UPLOAD=0`.
- Log retention keeps the newest 10 navigation runs by default.

## Field Test Commands

Local Piper baseline:

```bash
cd ~/blind_navigation_aid
source ~/blindnav-venv/bin/activate
export BLINDNAV_LOG_UPLOAD=1
export BLINDNAV_VOICE_INPUT=0
./tools/run_tts_local.sh
```

OpenAI alert TTS comparison:

```bash
cd ~/blind_navigation_aid
source ~/blindnav-venv/bin/activate
export OPENAI_API_KEY="sk-..."
export BLINDNAV_LOG_UPLOAD=1
export BLINDNAV_VOICE_INPUT=0
./tools/run_tts_openai.sh
```

Generate high-quality local alert clips:

```bash
cd ~/blind_navigation_aid
source ~/blindnav-venv/bin/activate
source ~/.config/blindnav/secrets.env
python3 tools/generate_alert_clips.py
```

The default generator now covers distance buckets from 0.2m through 3.2m,
including the observed field phrase `Stop! person on your left, 2.3 meters`.

Run local clip mode:

```bash
cd ~/blind_navigation_aid
source ~/blindnav-venv/bin/activate
export BLINDNAV_LOG_UPLOAD=1
export BLINDNAV_VOICE_INPUT=0
./tools/run_tts_clips.sh
```

Voice command input test:

```bash
cd ~/blind_navigation_aid
source ~/blindnav-venv/bin/activate
export OPENAI_API_KEY="sk-..."
export BLINDNAV_LOG_UPLOAD=1
export BLINDNAV_VOICE_INPUT=1
python3 raspberry_pi/yolo_realsense_navigation.py
```

Press `v` for a command when voice input is enabled.

## Log Behavior

- Completed runs create a CSV log and matching event log in `~/blindnav_logs`.
- If `BLINDNAV_LOG_UPLOAD=1`, cleanup starts an async uploader after both logs are closed.
- On the next startup, if upload is enabled, the newest previous completed run is retried.
- The newest 10 navigation runs are kept by default.
- Override retention with:

```bash
export BLINDNAV_LOG_RETENTION_RUNS=10
export BLINDNAV_UPLOAD_LOG_RETENTION=10
export BLINDNAV_LOG_RECOVERY_UPLOAD_RUNS=1
```

## Validation

- `python -m pytest tests/test_blindnav.py tests/test_blindnav_v326.py -q`
  - Current result: `200 passed`.
- `python -m py_compile raspberry_pi/yolo_realsense_navigation.py tools/generate_alert_clips.py tools/upload_run_logs_to_github.py tools/test_transcribe.py`
- `python tools/generate_alert_clips.py --list`
  - Current result: `294 phrase(s)`.

## Open Questions

- Do not replace safety alerts with cloud-only speech.
- Keep voice input disabled during TTS latency comparisons.
- If OpenAI TTS is slow, expensive, or unreliable, use cloud TTS only to generate local alert clips ahead of time.
- `BLINDNAV_ALERT_TTS=clips` is the preferred production candidate for high-quality fast safety speech.
- In clip-mode field logs, investigate every `mode=espeak_alert cache=fallback`
  line and add the missing phrase to `tools/generate_alert_clips.py`.
- JAX Whisper should not replace OpenAI STT on the Pi unless it is benchmarked under live YOLO/RealSense load and shown not to reduce detection FPS.

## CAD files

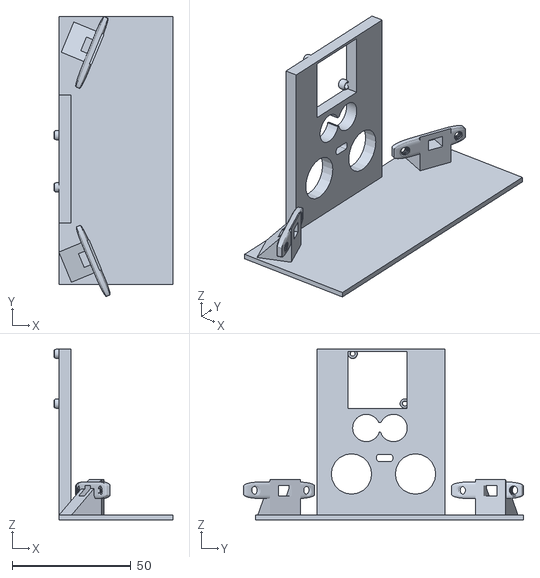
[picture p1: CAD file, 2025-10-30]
stl/sensor_prototype.stl
50.0 x 118.0 x 72.0

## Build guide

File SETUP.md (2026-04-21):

# Setup Guide

## Hardware

- Raspberry Pi 4
- Intel RealSense D435
- ICM-20948 IMU on I2C address `0x68`
- Bluetooth headphones using A2DP
- Chest harness with the camera angled slightly downward

## OS and System Packages

Start with Raspberry Pi OS Bookworm 64-bit.

```bash
sudo apt update && sudo apt upgrade -y
sudo apt install -y python3-pip python3-venv python3-opencv \
    libatlas-base-dev libasound2-dev espeak ffmpeg i2c-tools
```

Enable I2C:

```bash
sudo raspi-config
# Interface Options -> I2C -> Enable
```

## Python Environment

```bash
python3 -m venv ~/blindnav-venv
source ~/blindnav-venv/bin/activate
pip install numpy==1.26.4 onnxruntime opencv-python anthropic smbus2 pytest
```

Important notes:

- Do not install `numpy` 2.0+.
- Do not rely on PyPI `pyrealsense2` ARM wheels. Build or install the working
  ARM64 package already used on the Pi environment.

## YOLO26n Export

Export from a machine with `ultralytics` installed:

```bash
python3 - <<'PY'
from ultralytics import YOLO
model = YOLO("yolo26n.pt")
model.export(format="onnx", imgsz=224, opset=13, simplify=True)
PY
```

Copy to the Pi:

```bash
mkdir -p ~/yolo_models
scp yolo26n.onnx pi@raspberrypi:~/yolo_models/yolo26n.onnx
```

Verify the output shape:

```bash
python3 - <<'PY'
import onnxruntime as ort
sess = ort.InferenceSession("/home/pi/yolo_models/yolo26n.onnx",
                            providers=["CPUExecutionProvider"])
print(sess.get_outputs()[0].shape)
PY
```

Expected output: `(1, 300, 6)`

## Piper TTS

Install Piper and download the `en_US-amy-medium` voice model. The runtime
expects:

- `~/piper_voices/en_US-amy-medium.onnx`
- `~/piper_voices/en_US-amy-medium.onnx.json`

Optional voice overrides:

- `BLINDNAV_PIPER_VOICE=lessac-medium` to test `en_US-lessac-medium` from the
  same voice directory layout
- `BLINDNAV_PIPER_MODEL=/full/path/to/model.onnx`
- `BLINDNAV_PIPER_CONFIG=/full/path/to/model.onnx.json`

## IMU Wiring

| IMU Pin | Pi Pin |
|---|---|
| VCC | 3.3V |
| GND | GND |
| SDA | GPIO 2 |
| SCL | GPIO 3 |

Check the bus:

```bash
i2cdetect -y 1
```

## Run

```bash
source ~/blindnav-venv/bin/activate
export ANTHROPIC_API_KEY="sk-..."
python3 raspberry_pi/yolo_realsense_navigation.py
```

## Display Version

Do not use `cv2.imshow` on the Pi. For visual debugging, use the Flask MJPEG
display script and open `http://<pi-ip>:5000` from another device.

## Tests

These tests require no hardware:

```bash
pytest tests/test_blindnav.py tests/test_blindnav_v326.py -v
```

Expected current result: `174 passed`

## Health Checks Before Field Use

```bash
vcgencmd measure_temp
i2cdetect -y 1
hostname -I
```

Field-use rule: keep the Pi below 70 C before a walking session.

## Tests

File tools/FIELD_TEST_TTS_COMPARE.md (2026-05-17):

# BlindNav Alert TTS Field Test

Use these runs to compare only alert speech output. Detection, threat scoring,
queue policy, and `aplay` playback stay the same.

## Local baseline

```bash
source ~/blindnav-venv/bin/activate
./tools/run_tts_local.sh
```

Expected startup line:

```text
alert_tts=piper
```

## OpenAI alert TTS

```bash
source ~/blindnav-venv/bin/activate
export OPENAI_API_KEY="sk-..."
./tools/run_tts_openai.sh
```

Expected startup line:

```text
alert_tts=openai
```

## Local generated clips

Generate clips once before walking:

```bash
source ~/blindnav-venv/bin/activate
source ~/.config/blindnav/secrets.env
python3 tools/generate_alert_clips.py
```

Then run:

```bash
source ~/blindnav-venv/bin/activate
./tools/run_tts_clips.sh
```

Expected startup line:

```text
alert_tts=clips
clip_live_piper=off
```

## Compare

For each run, walk the same short course and save `~/blindnav_logs/events_*.log`.

Focus on `[LATENCY]` lines:

- `play_start`: user-perceived alert delay.
- `synth`: local Piper or OpenAI TTS generation time.
- `mode`: `piper_alert`, `openai_alert`, `clip_alert`, `espeak_alert`, or fallback.
- `cache`: `hit`, `miss`, `n/a`, or `fallback`.

Prefer clip mode if median and worst-case `play_start` improve without missed
phrases. Any `mode=espeak_alert cache=fallback` line means a phrase is missing
from the generated clip set and should be added before production use.

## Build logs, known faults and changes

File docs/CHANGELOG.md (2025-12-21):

# Changelog

## [2.1.0] - December 2024

### Added
- Visual distance estimation from bounding box sizes
- Sensor health monitoring with stuck detection
- Vision-primary sensor fusion strategy
- Threat assessment and prioritization system
- Confidence-based weighted fusion
- Graceful degradation on sensor failures
- Enhanced logging with distance source tracking
- Conflict detection and resolution
- Auto-save on critical threats

### Changed
- Upgraded to YOLOv11n from YOLOv8n
- Reduced track expiry from 2s to 1s (prevents lag)
- Increased IoU threshold from 0.3 to 0.4 (better matching)
- Improved detection interval handling
- Enhanced debugging output

### Fixed
- "Finger problem" - objects visible to camera but outside sensor FOV
- Ghost boxes from slow-moving objects
- Sensor failures going undetected
- Distance estimation for small objects
- Lag effect from expired tracks

### Performance
- 8-10 FPS on Pi 4B (up from 3.4 FPS)
- <100ms end-to-end latency
- ±3cm accuracy with sensor validation
- ±15cm accuracy visual-only mode

## [1.0.0] - November 2024

### Initial Release
- YOLOv8n object detection
- Basic sensor fusion
- LIDAR, TOF, and ultrasonic sensors
- ESP32 sensor hub
- Audio feedback via buzzer

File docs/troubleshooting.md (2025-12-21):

# Troubleshooting Guide

Common issues and solutions for the Blind Navigation Aid system.

## Table of Contents

1. [Installation Issues](#installation-issues)
2. [Camera Problems](#camera-problems)
3. [Sensor Issues](#sensor-issues)
4. [Detection Problems](#detection-problems)
5. [Performance Issues](#performance-issues)
6. [System Errors](#system-errors)

---

## Installation Issues

### Python Dependencies

**Problem:** `ModuleNotFoundError: No module named 'cv2'`

**Solution:**
```bash
# Install OpenCV
sudo apt install python3-opencv

# Or via pip
pip3 install opencv-python
```

**Problem:** `ImportError: libonnxruntime.so: cannot open shared object file`

**Solution:**
```bash
# Install ONNX Runtime
pip3 install onnxruntime

# For better performance, install optimized version
pip3 install onnxruntime-armv7l  # For Pi 3/4 32-bit
# or
pip3 install onnxruntime-aarch64  # For Pi 64-bit OS
```

### Serial Port Access

**Problem:** `serial.serialutil.SerialException: [Errno 13] Permission denied: '/dev/ttyUSB0'`

**Solution:**
```bash
# Add user to dialout group
sudo usermod -a -G dialout $USER

# Logout and login, or reboot
sudo reboot
```

**Problem:** ESP32 not detected at `/dev/ttyUSB0`

**Solution:**
```bash
# Check connected devices
ls -l /dev/tty*

# Common alternatives:
# /dev/ttyUSB1
# /dev/ttyACM0
# /dev/serial0

# Update ESP32_PORT in code
ESP32_PORT = "/dev/ttyACM0"  # Adjust as needed
```

---

## Camera Problems

### Camera Not Detected

**Problem:** `RuntimeError: Failed to open camera`

**Solution:**
```bash
# Check camera connection
vcgencmd get_camera

# Should show: supported=1 detected=1

# Enable camera interface
sudo raspi-config
# Interface Options → Camera → Enable

# Reboot
sudo reboot
```

### Poor Image Quality

**Problem:** Blurry or dark images

**Solution:**
```python
# Adjust camera controls in code
config = picam2.create_preview_configuration(
    main={"size": (640, 480), "format": "RGB888"},
    controls={
        "AwbEnable": True,
        "ExposureTime": 10000,  # Adjust for lighting
        "AnalogueGain": 2.0      # Increase for low light
    }
)
```

### Camera Orientation

**Problem:** Image is upside down

**Solution:**
```python
# Change rotation in code
frame_rgb = cv2.rotate(frame_rgb, cv2.ROTATE_180)  # Current
# or
frame_rgb = cv2.rotate(frame_rgb, cv2.ROTATE_90_CLOCKWISE)
```

---

## Sensor Issues

### LIDAR Not Responding

**Problem:** `latest_lidar_cm = None` always

**Solution:**
```bash
# Check serial connection
ls -l /dev/serial0

# Enable UART
sudo raspi-config
# Interface Options → Serial Port
# Login shell: NO
# Serial hardware: YES

# Check Raspberry Pi config
sudo nano /boot/config.txt
# Should have: enable_uart=1
```

**Problem:** LIDAR readings stuck at 0 or 800

**Solution:**
- Check wiring (TX→RX, RX→TX, GND, 5V)
- Verify baud rate matches (115200)
- Try different UART port
- Check for interference (keep away from motors)

### TOF Sensors Stuck

**Problem:** `TOF1(R): STUCK (conf=0.3)` warning

**Diagnosis:**
```
🔧 SENSOR HEALTH:
   TOF1(R): STUCK (conf=0.3) ⚠️
   # Sensor reporting same value for >0.8s
```

**Solutions:**

1. **Physical obstruction**
   ```bash
   # Check if something is blocking sensor
   # Remove any objects within 5cm
   ```

2. **Wiring issue**
   ```bash
   # Check I²C connections on ESP32
   # Verify SDA/SCL pins
   # Check for loose connections
   ```

3. **I²C address conflict**
   ```cpp
   // In ESP32 code, verify addresses
   VL53L0X sensor1;  // Address 0x29 (default)
   VL53L0X sensor2;  // Address 0x30 (after change)
   ```

4. **Sensor failure**
   - System will automatically downweight stuck sensor
   - Replace sensor if stuck persists

### Ultrasonic Erratic Readings

**Problem:** Ultrasonic jumps between values

**Solution:**
```python
# Increase median buffer size
ultra_buf = collections.deque(maxlen=5)  # Was 3

# Or add additional filtering
def smooth_ultrasonic(value, last_value):
    if abs(value - last_value) > 50:  # Spike
        return last_value  # Ignore
    return value
```

---

## Detection Problems

### No Objects Detected

**Problem:** `Tracked: 0` always

**Solution:**

1. **Check model path**
   ```python
   MODEL_PATH = os.path.expanduser("~/yolo_models/yolo11n.onnx")
   # Verify file exists
   print(f"Model exists: {os.path.exists(MODEL_PATH)}")
   ```

2. **Lower confidence threshold**
   ```python
   CONF_THRESH = 0.20  # Was 0.30
   ```

3. **Check camera view**
   ```python
   # Save raw frame to verify camera works
   cv2.imwrite("debug_frame.jpg", frame_display)
   ```

### Too Many False Positives

**Problem:** Detecting objects that aren't there

**Solution:**

1. **Increase confidence threshold**
   ```python
   CONF_THRESH = 0.40  # Was 0.30
   ```

2. **Increase NMS threshold**
   ```python
   NMS_THRESH = 0.50  # Was 0.45
   ```

3. **Filter by size**
   ```python
   # In yolo_postprocess, add minimum box size
   if (x2 - x1) < 20 or (y2 - y1) < 20:  # Was 10
       continue  # Skip tiny boxes
   ```

### Duplicate Detections

**Problem:** Multiple boxes on same object

**Solution:**

1. **Increase NMS threshold**
   ```python
   NMS_THRESH = 0.55  # Higher = more aggressive merging
   ```

2. **Increase tracking IoU**
   ```python
   best_iou = 0.5  # Was 0.4 in ObjectTracker
   ```

### Ghost Boxes (Lag)

**Problem:** Boxes remain after object moves

**Solution:**

1. **Reduce track expiry**
   ```python
   tracker = ObjectTracker(max_age=0.8)  # Was 1.0
   ```

2. **Increase IoU threshold**
   ```python
   best_iou = 0.45  # Higher = stricter matching
   ```

---

## Performance Issues

### Low FPS (<5)

**Problem:** System running slowly

**Solutions:**

1. **Reduce input size**
   ```python
   IMG_SIZE = 256  # Was 320
   ```

2. **Increase detection interval**
   ```python
   DETECTION_INTERVAL = 5  # Was 3 (detect every 5th frame)
   ```

3. **Disable display**
   ```python
   # Comment out imshow for headless operation
   # cv2.imshow("Intelligent Navigation", frame_display)
   ```

4. **Close other applications**
   ```bash
   # Check CPU usage
   htop
   
   # Kill unnecessary processes
   sudo systemctl stop bluetooth
   ```

5. **Overclock Pi (careful!)**
   ```bash
   sudo nano /boot/config.txt
   # Add:
   over_voltage=6
   arm_freq=2000
   gpu_freq=750
   ```

### High CPU Usage

**Problem:** CPU at 100% constantly

**Solution:**

1. **Enable camera hardware acceleration**
   ```python
   # Ensure using Picamera2 (hardware accelerated)
   # Not regular OpenCV VideoCapture
   ```

2. **Reduce camera framerate**
   ```python
   controls={"FrameRate": 15}  # Was 30
   ```

### Memory Issues

**Problem:** `MemoryError` or system freezing

**Solution:**

1. **Increase swap**
   ```bash
   sudo dphys-swapfile swapoff
   sudo nano /etc/dphys-swapfile
   # CONF_SWAPSIZE=2048  # Was 100
   sudo dphys-swapfile setup
   sudo dphys-swapfile swapon
   ```

2. **Reduce track history**
   ```python
   self.position_history = deque(maxlen=3)  # Was 5
   self.distance_history = deque(maxlen=3)  # Was 5
   ```

---

## System Errors

### ONNX Runtime Errors

**Problem:** `ONNXRuntimeError: The parameter is incorrect`

**Solution:**

1. **Check input shape**
   ```python
   print(f"Input shape: {img_in.shape}")
   # Should be (1, 3, 320, 320)
   ```

2. **Verify model compatibility**
   ```bash
   # Re-export model with correct opset
   # yolo export model=yolo11n.pt format=onnx opset=12
   ```

### Buzzer Not Working

**Problem:** No audio feedback

**Solution:**

1. **Check GPIO pin**
   ```python
   BUZZER_PIN = 18  # BCM numbering
   # Try different pin if needed
   ```

2. **Test buzzer manually**
   ```python
   import RPi.GPIO as GPIO
   GPIO.setmode(GPIO.BCM)
   GPIO.setup(18, GPIO.OUT)
   pwm = GPIO.PWM(18, 1000)
   pwm.start(50)
   # Should hear tone
   ```

3. **Check permissions**
   ```bash
   # Add user to gpio group
   sudo usermod -a -G gpio $USER
   ```

### CSV Logging Errors

**Problem:** `PermissionError: [Errno 13] Permission denied`

**Solution:**

1. **Check folder permissions**
   ```bash
   ls -ld ~/blindnav_logs
   # Should show drwxr-xr-x
   
   # Fix if needed
   chmod 755 ~/blindnav_logs
   ```

2. **Check disk space**
   ```bash
   df -h
   # Ensure sufficient space on /home
   ```

---

## Diagnostic Commands

### System Health Check

```bash
#!/bin/bash
echo "=== System Health Check ==="

echo "Camera:"
vcgencmd get_camera

echo "Temperature:"
vcgencmd measure_temp

echo "CPU freq:"
vcgencmd measure_clock arm

echo "Memory:"
free -h

echo "Disk:"
df -h /home

echo "USB devices:"
lsusb

echo "Serial ports:"
ls -l /dev/tty*

echo "Python packages:"
pip3 list | grep -E "opencv|onnx|picamera|serial"
```

### Run with Debug Output

```bash
# Enable verbose logging
python3 blind_nav_intelligent.py 2>&1 | tee debug.log

# Check logs
tail -f debug.log
```

### Monitor Resource Usage

```bash
# CPU and memory in real-time
htop

# GPU memory (camera)
vcgencmd get_mem gpu

# Temperature monitoring
watch -n 1 vcgencmd measure_temp
```

---

## Getting Help

If you're still having issues:

1. **Check logs**
   ```bash
   # System logs
   journalctl -xe
   
   # Application logs
   cat ~/blindnav_logs/log_*.csv
   ```

2. **Create issue on GitHub**
   - Include system info (`uname -a`)
   - Include Python version (`python3 --version`)
   - Include error messages
   - Include relevant code sections

3. **Test sensors individually**
   ```python
   # Create minimal test scripts
   # test_lidar.py, test_esp32.py, test_camera.py
   ```

---

## Common Error Messages

| Error | Likely Cause | Solution |
|---|---|---|
| `cv2.error: (-215:Assertion failed)` | Invalid image/frame | Check camera capture |
| `SerialException: device reports readiness` | Bad USB connection | Replug ESP32, check cable |
| `MemoryError` | Insufficient RAM | Reduce buffer sizes, increase swap |
| `ONNXRuntimeError` | Model/input mismatch | Verify model format and input shape |
| `GPIO.error` | Permission issue | Add user to gpio group |
| `Failed to open camera` | Camera not enabled | Run raspi-config |

---

**Last Updated:** December 2024  
**Version:** 2.1

For more help, open an issue at: https://github.com/Anthonyiswhy/blind_navigation_aid/issues

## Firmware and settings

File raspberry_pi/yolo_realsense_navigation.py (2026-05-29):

#!/usr/bin/env python3
"""
Intelligent Navigation Assistant v3.30 HEADLESS
Builds on v3.29 with:

  FIX 17 - Optional OpenAI alert TTS field-test mode.
    BLINDNAV_ALERT_TTS=openai sends urgent/warning/cleared alert speech to
    OpenAI text-to-speech using WAV output, while preserving the existing
    VoiceAssistant queue, no-SIGTERM aplay rule, latency logging, and local
    Piper/espeak fallback if cloud speech fails.

  FIX 16 - Push-to-talk voice command input.
    Optional voice input records a short command with arecord, transcribes it
    through OpenAI speech-to-text, and routes deterministic commands for
    describe, nearest, people, status, repeat, and cancel. Command capture and
    transcription run off the detection loop, while safety alerts stay on the
    local Piper/VoiceAssistant path.

  FIX 13 - Bucketed speech, broader cache reuse, and clearer voice diagnostics.
    Spoken distances now snap to stable 30cm voice buckets so the same warning
    phrases repeat instead of synthesizing slightly different decimals. Voice
    latency logs now separate queue wait, synth time, launch delay, cache hit
    vs miss, and whether the phrase came from prefetched Piper, cached Piper,
    or live synthesis.

  FIX 14 - Side-pass people are promoted before they are right on top of you.
    A person moving past on your left/right can have weak radial TTC even when
    they are a real navigation hazard. This version boosts nearby side-person
    scoring while the user is moving and adds a dedicated side-pass awareness/
    warning rule so those passes are spoken earlier.

  FIX 15 - Bad ego state no longer drives far or medium-range TTC chatter.
    When ego-motion confidence is bad, motion-derived TTC is now trusted only at
    close range while the user is still. This blocks nonsense alerts like
    "person ahead, 6.4 meters" while preserving close distance overrides.

  FIX 10 - Piper alerts by default, with cached urgent/warning clips.
    Amy-medium remains the default Piper voice, urgent/warning phrases use
    Piper instead of espeak, and common short safety phrases are prewarmed into
    a local clip cache to cut alert latency without giving up voice quality.

  FIX 11 - Shared filtered motion across scoring, TTC, logs, and CSV.
    Large depth jumps now require confirmation, small far-range drift is
    zeroed before it becomes fake approach velocity, and left/right/ahead uses
    wide-angle-aware hysteresis instead of a naive thirds split.

  FIX 12 - Shutdown is cleaner.
    Voice shutdown blocks new enqueues, clears pending speech safely, and the
    capture thread is joined during cleanup to avoid the post-exit abort path.

  FIX 8 — Urgent speech can supersede lower-priority synthesis safely.
    The v3.25 queue still allowed a bad case: a P2/P1 phrase could be in the
    middle of Piper synthesis when a P0 URGENT arrived, forcing urgent to wait
    for that lower-priority phrase to finish synthesizing and start playback.
    This version drops the lower-priority WAV only if a higher-priority alert
    becomes pending before aplay starts. Once audio playback has started, it is
    never terminated. This preserves the hard rule: NEVER send SIGTERM to
    aplay.

  FIX 9 — Partial neutral-wording fix in close-distance branches (Codex review).
    v3.25 gated "approaching" wording on ego_reliable in TTC branches but not
    in the very_close (<40cm) and close (<70cm) distance-override branches.
    Those branches use the `approaching` flag which derives from raw uncorrected
    velocity when ego is unreliable — wrong-perspective wording could still leak.
    Fix: gate `approaching` wording on `ego_reliable` in all three distance
    branches. When ego is unreliable -> neutral "{obj} {pos}, {dist}m" always.

INHERITED FROM v3.25:
  - YOLO 3 threads + SEQUENTIAL (Piper gets 1 core)
  - Ego-Z clamped to +/-160cm/s + confidence gating
  - Zone-based cooldown keys (survives track-ID churn)
  - Presyn semaphore (≤1 concurrent synthesis thread)
  - Per-alert latency timestamps in events.log
  - BT cold-start silence 150ms (was 300ms)
INHERITED FROM v3.24:
  - 3-slot priority queue, pre-synthesis, stream-cold silence
INHERITED FROM v3.23:
  - Velocity noise floor + TTC gate (>12s -> static)
  - Left/right/ahead position, richer CSV, events.log
INHERITED FROM v3.22:
  - Distance bucket cooldown keys, ThreatTransitionTracker velocity guard
  - IMU hysteresis (8 frames)
INHERITED FROM v3.21:
  - Wall/obstacle depth fallback, busy area detection
INHERITED FROM v3.17–v3.20:
  - Ego-motion compensation (LK + background depth)
  - YOLO26n NMS-free postprocess, pipelined capture, Piper TTS
"""
import os
import sys
import io
import time
import csv
import wave
import threading
import math
import re
import json
import hashlib
import shutil
import subprocess
import tempfile
import base64
import traceback
from datetime import datetime, timezone

import queue
import numpy as np
import cv2
import pyrealsense2 as rs
import onnxruntime as ort

# ============= CONFIGURATION =============
MODEL_PATH = os.path.expanduser("~/yolo_models/yolo26n.onnx")
IMG_SIZE = 224
DETECTION_INTERVAL = 2
CONF_THRESH = 0.38

CRITICAL_DISTANCE = 50
WARNING_DISTANCE = 150
SAFE_DISTANCE = 300

MAX_HUMAN_VELOCITY = 800
MAX_OBJECT_VELOCITY = 2000

MAX_DISTANCE_JUMP = 150
TRACK_IOU_THRESH = 0.30
DEPTH_CENTER_CROP_RATIO = 0.6
DEPTH_STRIDE = 2
MAX_DEPTH_SAMPLE_PIXELS = 4000

IGNORED_CLASSES = {
    "kite", "airplane", "boat", "train", "surfboard", "skis",
    "snowboard", "frisbee", "sports ball", "baseball bat",
    "baseball glove", "skateboard", "bird",
}

VOICE_ENABLED = True

WALL_DISTANCE_CM  = 80
WALL_CENTER_CROP  = 0.30
WALL_MIN_VALID_PX = 200
WALL_COOLDOWN_S   = 3.0

BUSY_TRACK_THRESHOLD = 4
BUSY_COOLDOWN_S      = 10.0
SPEAK_BUSY_AREA = (
    os.environ.get("BLINDNAV_SPEAK_BUSY_AREA", "0").strip().lower()
    in ("1", "true", "yes", "on")
)

VOICE_COOLDOWN = 5.0

PIPER_VOICE_NAME = os.environ.get("BLINDNAV_PIPER_VOICE", "amy-medium").strip() or "amy-medium"
PIPER_VOICE_DIR = os.path.expanduser(
    os.environ.get("BLINDNAV_PIPER_DIR", "~/piper_voices")
)
PIPER_MODEL  = os.path.expanduser(
    os.environ.get(
        "BLINDNAV_PIPER_MODEL",
        os.path.join(PIPER_VOICE_DIR, f"en_US-{PIPER_VOICE_NAME}.onnx"),
    )
)
PIPER_CONFIG = os.path.expanduser(
    os.environ.get("BLINDNAV_PIPER_CONFIG", PIPER_MODEL + ".json")
)
PIPER_SPEED  = 0.85
PIPER_SILENCE_MS = 150
ALERT_TTS_MODE = os.environ.get("BLINDNAV_ALERT_TTS", "piper").strip().lower()
if ALERT_TTS_MODE not in {"piper", "espeak", "openai", "clips"}:
    ALERT_TTS_MODE = "piper"
OPENAI_ALERT_TTS_MODEL = os.environ.get(
    "BLINDNAV_OPENAI_TTS_MODEL", "gpt-4o-mini-tts"
).strip() or "gpt-4o-mini-tts"
OPENAI_ALERT_TTS_VOICE = os.environ.get(
    "BLINDNAV_OPENAI_TTS_VOICE", "coral"
).strip() or "coral"
OPENAI_ALERT_TTS_TIMEOUT_S = max(
    1.0, float(os.environ.get("BLINDNAV_OPENAI_TTS_TIMEOUT_S", "4.0"))
)
OPENAI_ALERT_TTS_FALLBACK = os.environ.get(
    "BLINDNAV_OPENAI_TTS_FALLBACK", "1"
).strip().lower() not in {"0", "false", "no"}
OPENAI_ALERT_TTS_INSTRUCTIONS = os.environ.get(
    "BLINDNAV_OPENAI_TTS_INSTRUCTIONS",
    "Speak clearly, urgently when needed, and keep the phrase concise for a blind navigation safety alert.",
).strip()
ALERT_CACHE_DIR = os.path.expanduser(
    os.environ.get("BLINDNAV_ALERT_CACHE_DIR",
                   os.path.join(tempfile.gettempdir(), "blindnav_alert_cache"))
)
ALERT_CLIP_DIR = os.path.expanduser(
    os.environ.get("BLINDNAV_ALERT_CLIP_DIR", "~/blindnav_alert_clips")
)
CLIP_MODE_ALLOW_LIVE_PIPER = os.environ.get(
    "BLINDNAV_CLIP_MODE_ALLOW_LIVE_PIPER", "0"
).strip().lower() in {"1", "true", "yes", "on"}
ALERT_CACHE_PREWARM = os.environ.get(
    "BLINDNAV_ALERT_CACHE_PREWARM", "1"
).strip().lower() not in {"0", "false", "no"}
ALERT_DISTANCE_BUCKET_CM = 30
ALERT_SPOKEN_OFFSET_CM = 20
ALERT_CACHE_MAX_BUCKET = 5
ALERT_CACHE_POSITIONS = ("ahead", "on your left", "on your right")
ALERT_CACHE_COMMON_DISTANCES_M = tuple(
    ((bucket * ALERT_DISTANCE_BUCKET_CM) + ALERT_SPOKEN_OFFSET_CM) / 100.0
    for bucket in range(ALERT_CACHE_MAX_BUCKET + 1)
)
FAST_ALERT_SILENCE_MS = 220
ESPEAK_ALERT_SPEED = 175
ESPEAK_ALERT_GAP = 8
ESPEAK_ALERT_AMPLITUDE = 180

SIDE_PASS_PERSON_AWARE_CM = 150
SIDE_PASS_PERSON_WARN_CM = 110
MAX_VOICE_DISTANCE_CM = 320
BAD_EGO_TTC_MAX_DISTANCE_CM = 120
VOICE_POLICY_LOG_COOLDOWN_S = 2.0
GLOBAL_AWARENESS_COOLDOWN_S = 10.0
GLOBAL_CLEAR_COOLDOWN_S = 12.0
QUEUE_AWARENESS_WHEN_BUSY = os.environ.get(
    "BLINDNAV_QUEUE_AWARENESS_WHEN_BUSY", "0"
).strip().lower() in {"1", "true", "yes", "on"}
QUEUE_CLEAR_WHEN_BUSY = os.environ.get(
    "BLINDNAV_QUEUE_CLEAR_WHEN_BUSY", "0"
).strip().lower() in {"1", "true", "yes", "on"}
BLINDNAV_AUDIO_MODE = os.environ.get("BLINDNAV_AUDIO_MODE", "balanced").strip().lower()
if BLINDNAV_AUDIO_MODE not in {"quiet", "balanced", "training"}:
    BLINDNAV_AUDIO_MODE = "balanced"
PROXIMITY_TONES_ENABLED = os.environ.get(
    "BLINDNAV_PROXIMITY_TONES", "0"
).strip().lower() in {"1", "true", "yes", "on"}
PROXIMITY_TONES_DURING_VOICE = os.environ.get(
    "BLINDNAV_TONES_DURING_VOICE", "1"
).strip().lower() in {"1", "true", "yes", "on"}
TONE_REPLACES_OBSTACLE_VOICE = os.environ.get(
    "BLINDNAV_TONE_REPLACES_OBSTACLE_VOICE", "1"
).strip().lower() in {"1", "true", "yes", "on"}
PROXIMITY_TONE_VOLUME = max(
    0.0, min(1.0, float(os.environ.get("BLINDNAV_TONE_VOLUME", "0.35")))
)
PROXIMITY_TONE_MIN_CM = 35
PROXIMITY_TONE_VOICE_KEEP_CM = 90
PROXIMITY_TONE_URGENT_VOICE_KEEP_CM = 100
PROXIMITY_TONE_BALANCED_MAX_CM = 200
PROXIMITY_TONE_TRAINING_MAX_CM = MAX_VOICE_DISTANCE_CM
PROXIMITY_TONE_MIN_INTERVAL_S = 0.18
PROXIMITY_TONE_MAX_INTERVAL_S = 1.40
PROXIMITY_TONE_DURATION_S = 0.055
PROXIMITY_TONE_SAMPLE_RATE = 22050

POSITION_CAMERA_HFOV_DEG = 69.0
POSITION_SIDE_ENTER_DEG  = 13.1
POSITION_SIDE_EXIT_DEG   = 10.0
POSITION_SWITCH_FRAMES   = 2
POSITION_FORCE_SWITCH_DEG = 18.0

IMU_I2C_ADDR        = 0x68
IMU_MOTION_THRESHOLD = 0.05
IMU_WINDOW_SIZE     = 20
IMU_READ_INTERVAL   = 0.05
IMU_HYSTERESIS_FRAMES = 8
IMU_MAX_IO_ERRORS   = 3
IMU_REINIT_BACKOFF_S = 1.0

SCENE_MODEL       = "claude-haiku-4-5-20251001"
SCENE_MAX_TOKENS  = 150
SCENE_JPEG_QUALITY = 60
SCENE_COOLDOWN    = 8.0
SCENE_MAX_OBJECTS = 5

VOICE_INPUT_ENABLED = os.environ.get(
    "BLINDNAV_VOICE_INPUT", "0"
).strip().lower() in {"1", "true", "yes", "on"}
VOICE_INPUT_PTT_KEY = os.environ.get("BLINDNAV_PTT_KEY", "v").strip().lower() or "v"
VOICE_INPUT_CAPTURE_S = max(
    1.0, float(os.environ.get("BLINDNAV_COMMAND_CAPTURE_S", "4.0"))
)
VOICE_INPUT_STT_MODEL = os.environ.get(
    "BLINDNAV_STT_MODEL", "gpt-4o-mini-transcribe"
).strip() or "gpt-4o-mini-transcribe"
VOICE_INPUT_STT_TIMEOUT_S = max(
    1.0, float(os.environ.get("BLINDNAV_STT_TIMEOUT_S", "8.0"))
)
VOICE_INPUT_ARECORD_DEVICE = os.environ.get("BLINDNAV_ARECORD_DEVICE", "").strip()
VOICE_INPUT_GPIO = os.environ.get("BLINDNAV_PTT_GPIO", "").strip()

SNAPSHOT_FOLDER = os.path.expanduser("~/blindnav_snapshots")
os.makedirs(SNAPSHOT_FOLDER, exist_ok=True)

RECORD_TO_FILE = ""
PLAYBACK_FILE  = ""
PLAYBACK_REPEAT = True

BAG_FOLDER = os.path.expanduser("~/bags")
CSV_FOLDER = os.path.expanduser("~/blindnav_logs")
os.makedirs(BAG_FOLDER, exist_ok=True)
os.makedirs(CSV_FOLDER, exist_ok=True)
CSV_FILE = os.path.join(CSV_FOLDER, datetime.now(timezone.utc).strftime("log_%Y%m%d_%H%M%S.csv"))

LOG_UPLOAD_ENABLED = os.environ.get(
    "BLINDNAV_LOG_UPLOAD", "0"
).strip().lower() in {"1", "true", "yes", "on"}
LOG_UPLOAD_BRANCH = os.environ.get(
    "BLINDNAV_LOG_UPLOAD_BRANCH", "blindnav-field-logs"
).strip() or "blindnav-field-logs"
LOG_UPLOAD_REMOTE = os.environ.get("BLINDNAV_LOG_UPLOAD_REMOTE", "").strip()
LOG_RETENTION_RUNS = max(
    1, int(os.environ.get("BLINDNAV_LOG_RETENTION_RUNS", "10"))
)
LOG_UPLOAD_LOG_RETENTION = max(
    1, int(os.environ.get("BLINDNAV_UPLOAD_LOG_RETENTION", "10"))
)
LOG_RECOVERY_UPLOAD_RUNS = max(
    0, int(os.environ.get("BLINDNAV_LOG_RECOVERY_UPLOAD_RUNS", "1"))
)

# ============= YOLO CLASS NAMES =============
CLASS_NAMES = [
    "person", "bicycle", "car", "motorcycle", "airplane", "bus", "train", "truck", "boat",
    "traffic light", "fire hydrant", "stop sign", "parking meter", "bench", "bird", "cat",
    "dog", "horse", "sheep", "cow", "elephant", "bear", "zebra", "giraffe", "backpack",
    "umbrella", "handbag", "tie", "suitcase", "frisbee", "skis", "snowboard", "sports ball",
    "kite", "baseball bat", "baseball glove", "skateboard", "surfboard", "tennis racket",
    "bottle", "wine glass", "cup", "fork", "knife", "spoon", "bowl", "banana", "apple",
    "sandwich", "orange", "broccoli", "carrot", "hot dog", "pizza", "donut", "cake", "chair",
    "couch", "potted plant", "bed", "dining table", "toilet", "tv", "laptop", "mouse", "remote",
    "keyboard", "cell phone", "microwave", "oven", "toaster", "sink", "refrigerator", "book",
    "clock", "vase", "scissors", "teddy bear", "hair drier", "toothbrush"
]

OBJECT_THREAT_WEIGHTS = {
    "person": 1.5, "bicycle": 2.0, "car": 3.0, "motorcycle": 2.5,
    "truck": 3.5, "bus": 3.5, "train": 4.0, "dog": 1.3,
    "horse": 2.0, "bear": 4.0, "skateboard": 1.5,
    "chair": 0.8, "bench": 0.9, "potted plant": 0.7,
    "bottle": 0.3, "cup": 0.3, "couch": 0.6, "bed": 0.5,
    "dining table": 0.7,
}

# ============= ZONE-BASED VOICE KEY =============
_FURNITURE_CLASSES   = {"chair","couch","bed","bench","dining table","potted plant"}
_ELECTRONICS_CLASSES = {"tv","laptop","keyboard","mouse","remote","cell phone",
                        "microwave","oven","toaster"}
_VEHICLE_CLASSES     = {"car","truck","bus","motorcycle","bicycle"}

def _voice_key(pos: str, class_name: str, tier: str, dbucket: int = 0) -> str:
    if class_name in _FURNITURE_CLASSES:    family = "furniture"
    elif class_name in _ELECTRONICS_CLASSES: family = "electronics"
    elif class_name in _VEHICLE_CLASSES:    family = "vehicle"
    elif class_name == "person":            family = "person"
    else:                                   family = "object"
    zone = "left" if "left" in pos else "right" if "right" in pos else "center"
    return f"{zone}_{family}_{tier}_{dbucket}"


def _distance_bucket(dist_cm):
    if dist_cm is None or dist_cm < 0:
        return 0
    return max(0, int(dist_cm // ALERT_DISTANCE_BUCKET_CM))


def _bucket_distance_cm(dbucket):
    bucket = max(0, int(dbucket))
    return bucket * ALERT_DISTANCE_BUCKET_CM + ALERT_SPOKEN_OFFSET_CM


def _spoken_distance_m(dist_cm):
    return _bucket_distance_cm(_distance_bucket(dist_cm)) / 100.0


def _within_voice_distance(obj, dist_cm):
    if dist_cm is None or dist_cm < 0:
        return False
    return dist_cm <= MAX_VOICE_DISTANCE_CM


def _proximity_tone_max_distance(audio_mode=BLINDNAV_AUDIO_MODE):
    if audio_mode == "training":
        return PROXIMITY_TONE_TRAINING_MAX_CM
    if audio_mode == "balanced":
        return PROXIMITY_TONE_BALANCED_MAX_CM
    return 0


def _proximity_tone_interval_s(dist_cm, audio_mode=BLINDNAV_AUDIO_MODE):
    max_cm = _proximity_tone_max_distance(audio_mode)
    if dist_cm is None or dist_cm < 0 or max_cm <= 0 or dist_cm > max_cm:
        return None
    span = max(1.0, max_cm - PROXIMITY_TONE_MIN_CM)
    closeness = (max_cm - max(PROXIMITY_TONE_MIN_CM, dist_cm)) / span
    closeness = max(0.0, min(1.0, closeness))
    ratio = PROXIMITY_TONE_MIN_INTERVAL_S / PROXIMITY_TONE_MAX_INTERVAL_S
    return PROXIMITY_TONE_MAX_INTERVAL_S * (ratio ** closeness)


def _proximity_tone_gains(pos):
    if pos == "on your left":
        return 1.0, 0.18
    if pos == "on your right":
        return 0.18, 1.0
    return 0.85, 0.85


def _spoken_object_name(obj, tier):
    if obj == "person":
        return obj
    return "obstacle"


def _select_voice_decision(obj, pos, dist_cm, vel,
                           user_moving, ego_reliable,
                           approaching, very_close, close, fast_approach, ttc):
    if not _within_voice_distance(obj, dist_cm):
        return {
            "tier": None,
            "message": None,
            "reason": "beyond_voice_distance",
            "spoken_distance_m": _spoken_distance_m(dist_cm),
            "spoken_object": obj,
        }

    spoken_dist_m = _spoken_distance_m(dist_cm)
    side_pass_person = (
        obj == "person"
        and pos != "ahead"
        and dist_cm <= SIDE_PASS_PERSON_AWARE_CM
    )

    if very_close:
        spoken_obj = _spoken_object_name(obj, "urgent")
        if spoken_obj == "person" and approaching and ego_reliable and not user_moving:
            msg = f"{spoken_obj} {pos} approaching, {spoken_dist_m:.1f} meters"
            reason = "very_close_approach"
        elif approaching and ego_reliable and user_moving:
            msg = f"Stop! {spoken_obj} {pos}, {spoken_dist_m:.1f} meters"
            reason = "very_close_stop"
        else:
            msg = f"{spoken_obj} {pos}, {spoken_dist_m:.1f} meters"
            reason = "very_close_distance"
        return {
            "tier": "urgent",
            "message": msg,
            "reason": reason,
            "spoken_distance_m": spoken_dist_m,
            "spoken_object": spoken_obj,
        }

    if close:
        spoken_obj = _spoken_object_name(obj, "warning")
        if spoken_obj == "person" and approaching and ego_reliable and not user_moving:
            msg = f"{spoken_obj} {pos} closer, {spoken_dist_m:.1f} meters"
            reason = "close_person_closer"
        elif approaching and ego_reliable and user_moving:
            msg = f"Watch out, {spoken_obj} {pos}, {spoken_dist_m:.1f} meters"
            reason = "close_watch"
        else:
            msg = f"{spoken_obj} {pos}, {spoken_dist_m:.1f} meters"
            reason = "close_distance"
        return {
            "tier": "warning",
            "message": msg,
            "reason": reason,
            "spoken_distance_m": spoken_dist_m,
            "spoken_object": spoken_obj,
        }

    if side_pass_person:
        if dist_cm <= SIDE_PASS_PERSON_WARN_CM:
            return {
                "tier": "warning",
                "message": f"Watch out, person {pos}, {spoken_dist_m:.1f} meters",
                "reason": "side_pass_warning",
                "spoken_distance_m": spoken_dist_m,
                "spoken_object": "person",
            }
        return {
            "tier": "awareness",
            "message": f"person {pos}, {spoken_dist_m:.1f} meters",
            "reason": "side_pass_awareness",
            "spoken_distance_m": spoken_dist_m,
            "spoken_object": "person",
        }

    if ttc < 2:
        spoken_obj = _spoken_object_name(obj, "urgent")
        if spoken_obj == "person" and ego_reliable and fast_approach:
            msg = f"Stop! {spoken_obj} {pos}, {spoken_dist_m:.1f} meters"
            reason = "ttc_urgent_fast"
        elif spoken_obj == "person" and ego_reliable and approaching:
            msg = f"{spoken_obj} {pos} approaching, {spoken_dist_m:.1f} meters"
            reason = "ttc_urgent_approach"
        else:
            msg = f"{spoken_obj} {pos}, {spoken_dist_m:.1f} meters"
            reason = "ttc_urgent_neutral"
        return {
            "tier": "urgent",
            "message": msg,
            "reason": reason,
            "spoken_distance_m": spoken_dist_m,
            "spoken_object": spoken_obj,
        }

    if ttc < 4:
        spoken_obj = _spoken_object_name(obj, "warning")
        msg = (f"Watch out, {spoken_obj} {pos}, {spoken_dist_m:.1f} meters"
               if ego_reliable else f"{spoken_obj} {pos}, {spoken_dist_m:.1f} meters")
        return {
            "tier": "warning",
            "message": msg,
            "reason": "ttc_warning",
            "spoken_distance_m": spoken_dist_m,
            "spoken_object": spoken_obj,
        }

    if ttc < 8:
        spoken_obj = _spoken_object_name(obj, "awareness")
        return {
            "tier": "awareness",
            "message": f"{spoken_obj} {pos}, {spoken_dist_m:.1f} meters",
            "reason": "ttc_awareness",
            "spoken_distance_m": spoken_dist_m,
            "spoken_object": spoken_obj,
        }

    return {
        "tier": None,
        "message": None,
        "reason": "no_actionable_distance_or_ttc",
        "spoken_distance_m": spoken_dist_m,
        "spoken_object": obj,
    }


def _select_voice_message(obj, pos, dist_cm, vel,
                          user_moving, ego_reliable,
                          approaching, very_close, close, fast_approach, ttc):
    """
    Pure function: given threat state -> return (tier, message) or (None, None).

    tier: 'urgent' | 'warning' | 'awareness' | None
    Extracted from main() so it can be unit-tested without hardware.

    ego_reliable gates ALL directional ("approaching", "closer") wording.
    When unreliable -> neutral "{obj} {pos}, {dist}m" at appropriate tier.
    """
    decision = _select_voice_decision(
        obj, pos, dist_cm, vel,
        user_moving, ego_reliable,
        approaching, very_close, close, fast_approach, ttc)
    return decision["tier"], decision["message"]


def _queue_tier_for_voice_decision(tier, reason):
    if reason == "side_pass_warning":
        return "urgent"
    return tier


def _tone_replaces_voice(queue_tier, obj, reason, dist_cm, tones_enabled):
    if (not tones_enabled or not TONE_REPLACES_OBSTACLE_VOICE
            or queue_tier is None or obj == "person"):
        return False
    if dist_cm is None or dist_cm < 0:
        return False
    if queue_tier == "urgent":
        return reason.startswith("ttc_") and dist_cm > PROXIMITY_TONE_URGENT_VOICE_KEEP_CM
    return queue_tier in {"warning", "awareness"} and dist_cm > PROXIMITY_TONE_VOICE_KEEP_CM


def _repo_root():
    return os.path.abspath(os.path.join(os.path.dirname(__file__), os.pardir))
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

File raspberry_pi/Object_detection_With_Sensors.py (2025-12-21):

#!/usr/bin/env python3
"""
blind_nav_intelligent.py
INTELLIGENT NAVIGATION SYSTEM
- YOLOv8n support
- Object tracking with velocity calculation
- Threat assessment and prioritization
- Sensor fusion with directional awareness
"""
import os
import time
import csv
import threading
from datetime import datetime
import collections
import math

import numpy as np
import cv2
import serial
import onnxruntime as ort
from picamera2 import Picamera2
import RPi.GPIO as GPIO

# ============= CONFIG =============
ESP32_PORT = "/dev/ttyUSB0"
ESP32_BAUD = 115200

LIDAR_PORT = "/dev/serial0"
LIDAR_BAUD = 115200

MODEL_PATH = os.path.expanduser("~/yolo_models/yolo11n.onnx")  # YOLOv11n
IMG_SIZE = 320
DETECTION_INTERVAL = 3  # Every 3 frames for better FPS
CONF_THRESH = 0.30  # Higher to reduce false positives
NMS_THRESH = 0.45

# Visual distance estimation (fallback when sensors can't see object)
ENABLE_VISUAL_DISTANCE = True  # Estimate distance from bounding box size
DEBUG_LOGGING = True  # Enhanced logging for diagnostics

# Threat assessment thresholds
CRITICAL_DISTANCE = 50   # cm - immediate danger
WARNING_DISTANCE = 150   # cm - need attention
SAFE_DISTANCE = 300      # cm - awareness only

BUZZER_PIN = 18
BUZZER_MIN_FREQ = 400
BUZZER_MAX_FREQ = 1500

AUTO_SAVE_DETECTIONS = True
SNAPSHOT_FOLDER = os.path.expanduser("~/blindnav_snapshots")
os.makedirs(SNAPSHOT_FOLDER, exist_ok=True)

CSV_FOLDER = os.path.expanduser("~/blindnav_logs")
os.makedirs(CSV_FOLDER, exist_ok=True)
CSV_FILE = os.path.join(CSV_FOLDER, datetime.utcnow().strftime("log_%Y%m%d_%H%M%S.csv"))

# ============= GLOBALS =============
run_flag = True
esp32_data = {"tof1": -1, "tof2": -1, "ultrasonic": -1}
esp_lock = threading.Lock()

latest_lidar_cm = None
lidar_lock = threading.Lock()

# Median buffers
lidar_buf = collections.deque(maxlen=3)
tof1_buf = collections.deque(maxlen=3)
tof2_buf = collections.deque(maxlen=3)
ultra_buf = collections.deque(maxlen=3)

# YOLO class names
CLASS_NAMES = [
    "person", "bicycle", "car", "motorcycle", "airplane", "bus", "train", "truck", "boat",
    "traffic light", "fire hydrant", "stop sign", "parking meter", "bench", "bird", "cat",
    "dog", "horse", "sheep", "cow", "elephant", "bear", "zebra", "giraffe", "backpack",
    "umbrella", "handbag", "tie", "suitcase", "frisbee", "skis", "snowboard", "sports ball",
    "kite", "baseball bat", "baseball glove", "skateboard", "surfboard", "tennis racket",
    "bottle", "wine glass", "cup", "fork", "knife", "spoon", "bowl", "banana", "apple",
    "sandwich", "orange", "broccoli", "carrot", "hot dog", "pizza", "donut", "cake", "chair",
    "couch", "potted plant", "bed", "dining table", "toilet", "tv", "laptop", "mouse", "remote",
    "keyboard", "cell phone", "microwave", "oven", "toaster", "sink", "refrigerator", "book",
    "clock", "vase", "scissors", "teddy bear", "hair drier", "toothbrush"
]

# Object type threat weights
OBJECT_THREAT_WEIGHTS = {
    "person": 1.5,
    "bicycle": 2.0,
    "car": 3.0,
    "motorcycle": 2.5,
    "truck": 3.5,
    "bus": 3.5,
    "train": 4.0,
    "dog": 1.3,
    "chair": 0.8,
    "bench": 0.9,
    "potted plant": 0.7,
    "bottle": 0.3,
    "cup": 0.3,
}

CLASS_COLORS = {
    "person": (0, 255, 0),
    "car": (255, 0, 0),
    "bicycle": (255, 128, 0),
    "motorcycle": (255, 64, 0),
    "truck": (200, 0, 0),
    "chair": (0, 255, 255),
    "bottle": (255, 255, 0),
}
DEFAULT_COLOR = (0, 255, 255)

last_save_time = 0
SAVE_COOLDOWN = 3

# ============= OBJECT TRACKER CLASS =============
class ObjectTracker:
    """Track objects across frames to calculate velocity."""
    
    def __init__(self, max_age=1.0):  # Reduced from 30 frames to 1 second
        self.tracks = {}  # {track_id: Track}
        self.next_id = 0
        self.max_age = max_age  # seconds before track expires
    
    def update(self, detections, current_time):
        """Update tracks with new detections."""
        # Age out old tracks - FASTER expiration
        expired = [tid for tid, track in self.tracks.items() 
                  if current_time - track.last_seen > self.max_age]
        for tid in expired:
            del self.tracks[tid]
        
        # Match detections to existing tracks
        if not detections:
            return list(self.tracks.values())
        
        matched = []
        for det in detections:
            best_match = None
            best_iou = 0.4  # HIGHER threshold to prevent mismatches (was 0.3)
            
            for tid, track in self.tracks.items():
                if tid in matched:
                    continue
                if track.class_name != det['class_name']:
                    continue
                
                iou = self._calculate_iou(track.box, det['box'])
                if iou > best_iou:
                    best_iou = iou
                    best_match = tid
            
            if best_match:
                self.tracks[best_match].update(det, current_time)
                matched.append(best_match)
            else:
                # New track
                new_track = Track(self.next_id, det, current_time)
                self.tracks[self.next_id] = new_track
                self.next_id += 1
        
        return list(self.tracks.values())
    
    def _calculate_iou(self, box1, box2):
        """Calculate intersection over union."""
        x1 = max(box1[0], box2[0])
        y1 = max(box1[1], box2[1])
        x2 = min(box1[2], box2[2])
        y2 = min(box1[3], box2[3])
        
        if x2 < x1 or y2 < y1:
            return 0.0
        
        inter = (x2 - x1) * (y2 - y1)
        area1 = (box1[2] - box1[0]) * (box1[3] - box1[1])
        area2 = (box2[2] - box2[0]) * (box2[3] - box2[1])
        union = area1 + area2 - inter
        
        return inter / union if union > 0 else 0.0
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

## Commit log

2026-03-20 v3.22: distance bucket keys, transition tracker guard, IMU hysteresis
2026-04-19 v3.26b: use BT-safe skip-ahead
    [yolo_realsense_navigation.py]
2026-04-20 v3.26b: recover IMU via auto-reinit on I/O faults
2026-04-20 v3.27: fast alert TTS and bad-ego velocity guard
2026-04-21 v3.27: stabilize alerts and shutdown
    [yolo_realsense_navigation.py]
2026-04-21 v3.27: switch alerts to cached Piper clips
2026-04-21 v3.28: cut phrase latency and speak side-pass people
2026-04-24 Fix RealSense capture shutdown race
    [yolo_realsense_navigation.py]
2026-05-29 Prevent voice command prompt echo cancel
    [yolo_realsense_navigation.py]
2026-05-29 v3.31: Fix bugs and add thermal monitoring
    - Fix argument mismatch in `Object_detection_With_Sensors.py`
    - Add CPU temperature monitoring to `yolo_realsense_navigation.py`
    - Report temperature in the "status" voice command
    - Throttle temperature checks to 10s to avoid per-frame overhead
    - Harden `ThreatTransitionTracker` to only use valid velocities for directional clear messages
    - Verified all 219 tests pass locally
    [Object_detection_With_Sensors.py, yolo_realsense_navigation.py]
2026-06-01 Revert "Fix bugs and enhance thermal monitoring"
    [Object_detection_With_Sensors.py, yolo_realsense_navigation.py]
